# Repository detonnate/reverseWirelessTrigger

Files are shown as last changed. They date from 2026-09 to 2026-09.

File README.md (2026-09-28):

# ESP32 Wireless Reverse Trigger

A tested wireless reverse-trigger system for vehicles using two ESP32-C3 SuperMini boards and ESP-NOW. It was developed to add an automatic reverse-camera trigger to an aftermarket head unit **without running a trigger wire from the rear of the vehicle to the dashboard**.

> **Status:** Prototype tested and working.

## How it works

The rear transmitter is powered from the vehicle's reverse-light circuit. When reverse is selected it powers up and broadcasts a heartbeat over ESP-NOW every 75 ms. The front receiver is powered from ignition/ACC. While valid heartbeats are received it drives GPIO 4 HIGH, activating a 3.3 V HIGH-level relay module. The relay then supplies +12 V to the head unit's reverse-trigger input.

If the radio heartbeat disappears for more than 400 ms, the receiver switches the relay off. The existing wireless video link/camera is independent of this project.

## Hardware used

- 2 × ESP32-C3 SuperMini USB-C boards
- 2 × automotive 12 V → 5 V USB-C converters
- 2 × 1 A inline fuses
- 1 × 3.3 V HIGH-level single-channel relay module
- Automotive wire/connectors/heat-shrink
- Rear: off-the-shelf waterproof enclosure
- Front: custom enclosure (STL folder provided for the design)

## Wiring

### Rear / transmitter

```text
Reverse-light +12 V -> 1 A fuse -> 12 V-to-5 V USB-C converter + input
Vehicle GND ---------------------> converter - input
USB-C converter -----------------> ESP32-C3 USB-C
```

No GPIO wiring is required at the rear. The transmitter firmware assumes that if the ESP32 has power, reverse is active.

### Front / receiver

```text
ACC +12 V -> 1 A fuse -> 12 V-to-5 V USB-C converter + input
Vehicle GND ------------> converter - input
USB-C converter --------> ESP32-C3 USB-C

ESP32 3V3  -------------> Relay VCC / +
ESP32 GND  -------------> Relay GND / -
ESP32 GPIO 4 -----------> Relay IN / S

ACC +12 V --------------> Relay COM
Relay NO ----------------> Head-unit reverse-trigger input
Relay NC ----------------> Not used
```

The relay module is the **3.3 V HIGH-level** variant. The contacts switch the vehicle's 12 V trigger signal; 3.3 V is only used to power/control the relay module.

**Verify that your particular head unit expects +12 V on its reverse-trigger input before connecting it.**

## Firmware

- `firmware/transmitter/ReverseTrigger_TX.ino`
- `firmware/receiver/ReverseTrigger_RX.ino`

Both sketches must use the same `DEVICE_ID` and `ESPNOW_CHANNEL`.

Current defaults:

```cpp
DEVICE_ID = 0x72A91F31
ESPNOW_CHANNEL = 1
SEND_INTERVAL_MS = 75
SIGNAL_TIMEOUT_MS = 400
RELAY_PIN = GPIO 4
```

The firmware uses the newer ESP-NOW receive callback API used by current ESP32 Arduino/ESP-IDF packages. The transmitter deliberately does not register a send callback, avoiding callback-signature differences seen in newer ESP32-C3 packages.

## Arduino setup

1. Install Arduino IDE and Espressif's ESP32 board support.
2. Connect the rear ESP32-C3 over USB-C.
3. Open `ReverseTrigger_TX.ino`, select the appropriate ESP32-C3 board/port and upload.
4. Connect the front ESP32-C3.
5. Open `ReverseTrigger_RX.ino` and upload.
6. Bench-test before installing in the vehicle.

## Enclosure

The rear electronics use an off-the-shelf waterproof enclosure, so no custom rear STL is required.

The front/head-unit enclosure is intended to hold the receiver-side ESP32-C3, relay module and associated wiring. Put printable models in:

`enclosure/head-unit/STL/`

Put editable CAD/source files in:

`enclosure/head-unit/source/`

A placeholder is included until the final enclosure dimensions and STL are completed.

## Repository structure

```text
Wireless-Reverse-Trigger/
├── README.md
├── LICENSE
├── .gitignore
├── firmware/
│   ├── transmitter/
│   │   └── ReverseTrigger_TX.ino
│   └── receiver/
│       └── ReverseTrigger_RX.ino
├── hardware/
│   └── wiring/
│       └── README.md
├── enclosure/
│   ├── head-unit/
│   │   ├── STL/
│   │   │   └── README.md
│   │   └── source/
│   │       └── README.md
│   └── rear-unit/
│       └── README.md
├── docs/
│   └── BUILD.md
└── images/
    └── README.md
```

## Safety / production notes

This repository documents a working prototype, not an automotive-qualified production product. Vehicle electrical systems can experience transients and load-dump events. A commercial version should use automotive-rated power protection, EMC/RED testing as applicable, protected outputs, robust pairing/authentication and appropriate regulatory/compliance work.

The prototype uses a shared `DEVICE_ID` and unencrypted ESP-NOW broadcast. Do not treat that as secure authentication for a commercial product.

## License

MIT — see `LICENSE`.

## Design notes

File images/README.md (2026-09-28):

# Images

Repository screenshots, installed-unit photographs and wiring illustrations can be stored here.

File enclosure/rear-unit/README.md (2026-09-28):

# Rear Enclosure

The tested prototype uses an off-the-shelf waterproof project box at the reverse-light/transmitter end. No custom STL is currently required.

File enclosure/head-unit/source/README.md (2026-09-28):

# Enclosure CAD Source

Place editable enclosure source files here (for example Fusion 360 export, STEP, FreeCAD or OpenSCAD source). Keep the STL exports in the sibling `STL` folder.

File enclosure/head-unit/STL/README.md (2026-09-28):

# Head-Unit Enclosure STL

Place the final 3D-printable `.stl` files for the front/head-unit enclosure here.

Suggested eventual files:
- `head_unit_enclosure_base.stl`
- `head_unit_enclosure_lid.stl`

The final model should be dimensioned from the actual ESP32-C3, relay module, USB-C converter/cable routing and preferred mounting method before printing.

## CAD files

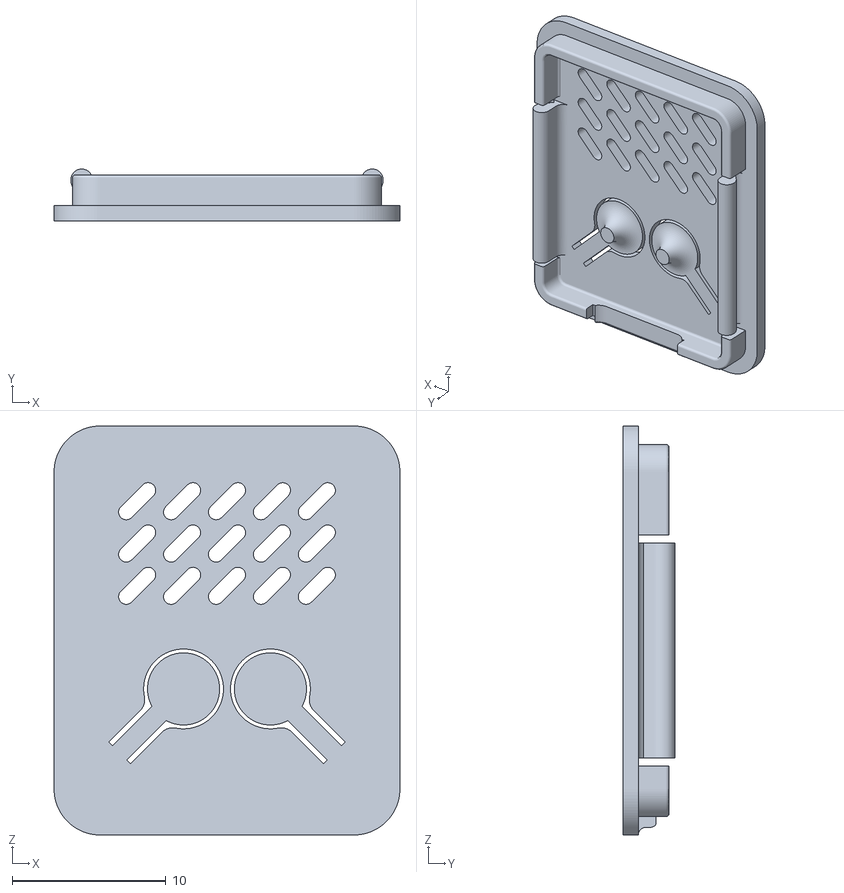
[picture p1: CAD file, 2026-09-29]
enclosure/head-unit/STL/Tapa_C3_SuperMini_Buttons.stl
22.5 x 3.39 x 26.6

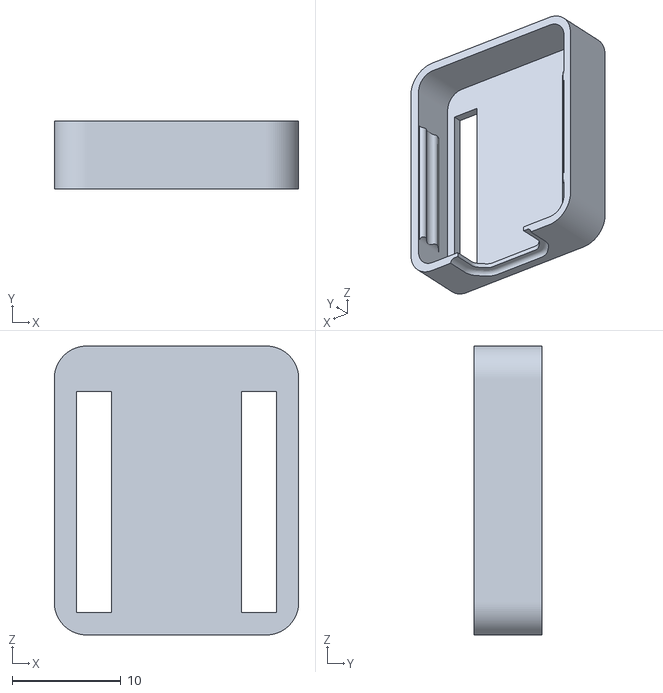
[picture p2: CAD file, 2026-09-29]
enclosure/head-unit/STL/Bottom_C3_SuperMini.stl
22.5 x 6.25 x 26.6

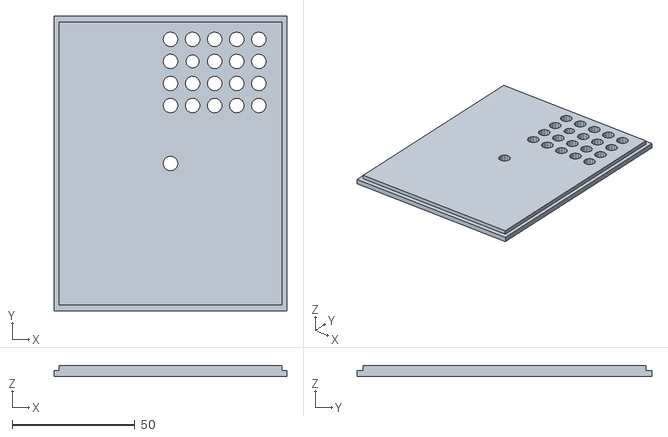
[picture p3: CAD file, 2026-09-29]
enclosure/head-unit/STL/Reverse Box Lid.stl
95.0 x 120.2 x 4.50

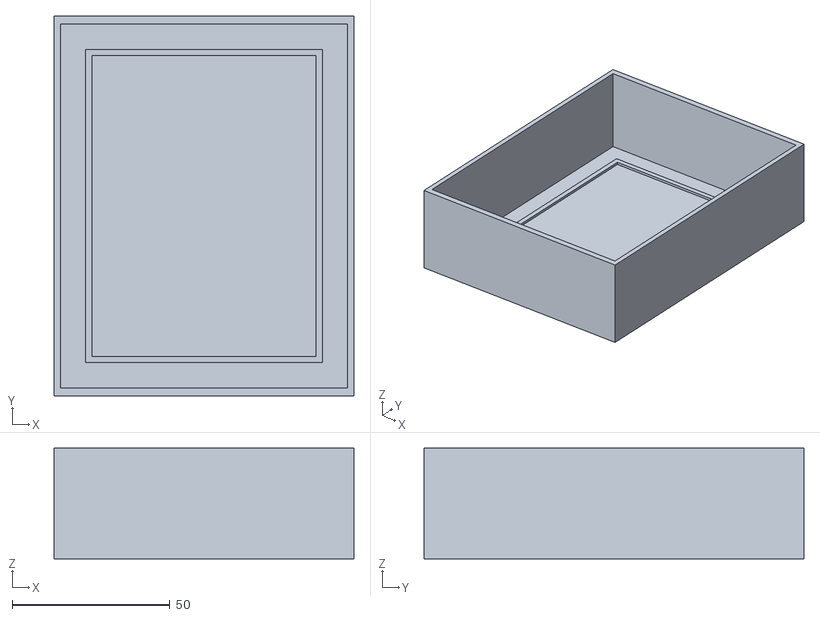
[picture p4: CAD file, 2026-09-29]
enclosure/head-unit/STL/Reverse Box.stl
95.0 x 120.2 x 35.0

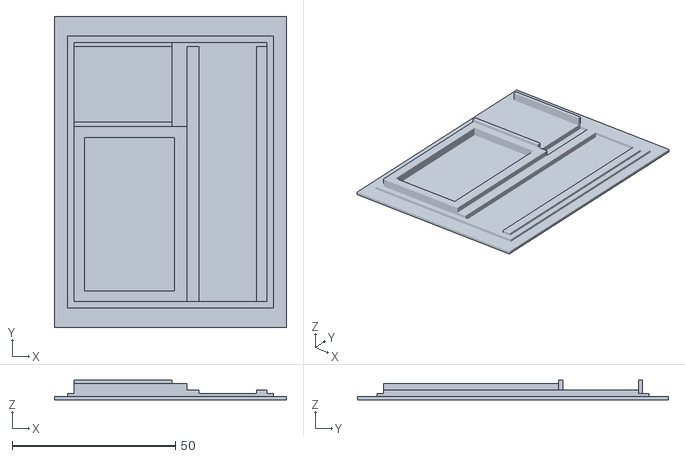
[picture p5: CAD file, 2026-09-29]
enclosure/head-unit/STL/Reverse Box Inner.stl
71.0 x 95.2 x 6.00

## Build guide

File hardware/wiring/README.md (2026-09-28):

# Wiring Documentation

Store wiring diagrams, schematics and PCB information here.

Current prototype:
- Rear: reverse-light 12 V -> fused USB-C converter -> ESP32-C3.
- Front: ACC 12 V -> fused USB-C converter -> ESP32-C3.
- ESP32 front: 3V3 -> relay VCC, GND -> relay GND, GPIO4 -> relay IN.
- Relay: COM -> +12 V ACC, NO -> head-unit reverse input, NC unused.

The relay module is the 3.3 V HIGH-level variant.

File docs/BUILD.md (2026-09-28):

# Build Guide

## 1. Program both ESP32-C3 boards
Upload the transmitter sketch to the rear board and the receiver sketch to the front board. Keep `DEVICE_ID` and `ESPNOW_CHANNEL` identical.

## 2. Bench-test the wireless link
Power the receiver first. Power the transmitter. GPIO 4 should go HIGH and the 3.3 V HIGH-level relay should energise. Remove transmitter power; the relay should release after approximately 400 ms.

## 3. Rear installation
Take fused +12 V from the reverse-light circuit and ground from a suitable vehicle ground. Feed these into the 12 V-to-5 V USB-C converter and plug the converter into the transmitter ESP32. Mount the electronics in the off-the-shelf waterproof enclosure.

## 4. Front installation
Take fused ignition/ACC +12 V and ground to the front USB-C converter. Plug it into the receiver ESP32. Connect ESP32 3V3, GND and GPIO 4 to the corresponding relay module power, ground and trigger input.

Connect fused/appropriate ACC +12 V to relay COM. Connect relay NO to the head unit's reverse-trigger input. Leave NC unused.

## 5. Final test
With ignition on and the vehicle safely stationary, verify the receiver is powered but the relay is off. Select reverse: the rear unit powers, the receiver detects it, and the relay supplies +12 V to the head-unit reverse input. Exit reverse: the relay should release after the timeout.

## Important
- Confirm the head unit expects a +12 V reverse trigger.
- Never feed vehicle 12 V directly into an ESP32 GPIO/3V3/5V pin.
- Verify converter output before first connection.
- Fuse both vehicle-side supplies.
- Secure and insulate all wiring before road use.

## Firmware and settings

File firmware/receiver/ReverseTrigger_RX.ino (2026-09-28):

#include <WiFi.h>
#include <esp_now.h>
#include <esp_wifi.h>

const uint32_t DEVICE_ID = 0x72A91F31;
const uint8_t ESPNOW_CHANNEL = 1;
const int RELAY_PIN = 4;
const unsigned long SIGNAL_TIMEOUT_MS = 400;

unsigned long lastValidPacket = 0;
bool reverseActive = false;

struct ReversePacket {
  uint32_t deviceID;
  uint32_t counter;
  uint8_t reverseActive;
};

void reverseOn() {
  if (!reverseActive) {
    reverseActive = true;
    digitalWrite(RELAY_PIN, HIGH); // 3.3 V HIGH-level relay module
    Serial.println("\n*** REVERSE ON ***\n");
  }
}

void reverseOff() {
  if (reverseActive) {
    reverseActive = false;
    digitalWrite(RELAY_PIN, LOW);
    Serial.println("\n*** REVERSE OFF ***\n");
  }
}

void onDataReceived(const esp_now_recv_info_t *info, const uint8_t *incomingData, int len) {
  if (len != sizeof(ReversePacket)) return;

  ReversePacket receivedPacket;
  memcpy(&receivedPacket, incomingData, sizeof(receivedPacket));

  if (receivedPacket.deviceID != DEVICE_ID) return;

  if (receivedPacket.reverseActive == 1) {
    lastValidPacket = millis();
    reverseOn();
    Serial.print("Heartbeat received: ");
    Serial.println(receivedPacket.counter);
  }
}

void setup() {
  Serial.begin(115200);
  pinMode(RELAY_PIN, OUTPUT);
  digitalWrite(RELAY_PIN, LOW);
  delay(500);

  Serial.println("\n==============================");
  Serial.println("WIRELESS REVERSE TRIGGER");
  Serial.println("FRONT RECEIVER");
  Serial.println("==============================");

  WiFi.mode(WIFI_STA);
  WiFi.disconnect();
  delay(100);

  esp_wifi_set_channel(ESPNOW_CHANNEL, WIFI_SECOND_CHAN_NONE);

  Serial.print("RX MAC Address: ");
  Serial.println(WiFi.macAddress());

  if (esp_now_init() != ESP_OK) {
    Serial.println("ERROR: ESP-NOW failed to initialise.");
    while (true) {
      digitalWrite(RELAY_PIN, LOW);
      delay(1000);
    }
  }

  esp_now_register_recv_cb(onDataReceived);
  Serial.println("RECEIVER READY");
  Serial.println("Waiting for rear transmitter...");
}

void loop() {
  if (reverseActive && (millis() - lastValidPacket > SIGNAL_TIMEOUT_MS)) {
    reverseOff();
  }
  delay(5);
}

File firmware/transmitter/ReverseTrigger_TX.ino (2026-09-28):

#include <WiFi.h>
#include <esp_now.h>
#include <esp_wifi.h>

const uint32_t DEVICE_ID = 0x72A91F31;
const uint8_t ESPNOW_CHANNEL = 1;
const unsigned long SEND_INTERVAL_MS = 75;

uint8_t broadcastAddress[] = {0xFF,0xFF,0xFF,0xFF,0xFF,0xFF};

struct ReversePacket {
  uint32_t deviceID;
  uint32_t counter;
  uint8_t reverseActive;
};

ReversePacket packet;
unsigned long lastSendTime = 0;
uint32_t packetCounter = 0;

void setup() {
  Serial.begin(115200);
  delay(500);

  Serial.println("\n==============================");
  Serial.println("WIRELESS REVERSE TRIGGER");
  Serial.println("REAR TRANSMITTER");
  Serial.println("==============================");

  WiFi.mode(WIFI_STA);
  WiFi.disconnect();
  delay(100);

  esp_wifi_set_channel(ESPNOW_CHANNEL, WIFI_SECOND_CHAN_NONE);

  Serial.print("TX MAC Address: ");
  Serial.println(WiFi.macAddress());

  if (esp_now_init() != ESP_OK) {
    Serial.println("ERROR: ESP-NOW failed to initialise.");
    while (true) delay(1000);
  }

  esp_now_peer_info_t peerInfo = {};
  memcpy(peerInfo.peer_addr, broadcastAddress, 6);
  peerInfo.channel = ESPNOW_CHANNEL;
  peerInfo.encrypt = false;

  if (esp_now_add_peer(&peerInfo) != ESP_OK) {
    Serial.println("ERROR: Failed to add broadcast peer.");
    while (true) delay(1000);
  }

  Serial.println("TRANSMITTER READY\n");
}

void loop() {
  unsigned long now = millis();
  if (now - lastSendTime >= SEND_INTERVAL_MS) {
    lastSendTime = now;
    packet.deviceID = DEVICE_ID;
    packet.counter = packetCounter++;
    packet.reverseActive = 1;

    esp_err_t result = esp_now_send(broadcastAddress, (uint8_t *)&packet, sizeof(packet));
    if (result == ESP_OK) {
      Serial.print("Reverse heartbeat sent: ");
      Serial.println(packet.counter);
    } else {
      Serial.print("Send error: ");
      Serial.println(result);
    }
  }
}

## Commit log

2026-09-28 Initial project snapshot
    [Reverse Box 2.stl, Reverse Box 3.stl, Reverse Box Inner.stl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]
2026-09-29 Update head-unit enclosure STL files
    [Reverse Box 2.stl, Reverse Box 3.stl, Reverse Box Inner.stl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]
2026-09-29 Add enclosure STL models
    [Bottom_C3_SuperMini.stl, Tapa_C3_SuperMini_Buttons.stl]
